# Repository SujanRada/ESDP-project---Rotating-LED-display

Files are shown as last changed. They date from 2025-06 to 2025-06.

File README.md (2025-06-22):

# Rotating LED Display

## Abstract

- Compact, disc-sized device  
- Rotates using CD/BLDC motor  
- Uses 56 RGB LEDs to display images, time, weather, and data from the internet  
- Wirelessly powered  
- Controlled via user-friendly web interfaces  
- Uses ESP-32 and RP-2040 microcontrollers
  
### BOM:
https://iith-my.sharepoint.com/:x:/g/personal/ee23btech11220_iith_ac_in/Eb25p-EQcuBLmObKBZ19a6YB39MDdF6vqVOBd3wfBGQ2Pw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

## Description of the Device

- Two primary units:
  - Power supply unit (stationary)
  - Display board (rotates)

- Wireless power using inductive coupling  
- Display board is rotated using a DC motor  
- Energy is wirelessly transmitted from the power supply unit to the display board, eliminating the use of wired connections  
- Display board has a row of 56 LEDs used for display. As the board rotates, the LEDs light up to create full images using the POV (Persistence of Vision) effect  
- LED operations are controlled by the RP-2040  
- ESP32 controls the display content, image decoding, and Wi-Fi connectivity (maintains an internet connection)  
- Images are stored on a microSD card  
- Web interface hosted by ESP32 (mini web server). Users can access it via any browser to:
  - Enter/change Wi-Fi credentials
  - Upload and manage files
  - Modify display settings
 
## Device
<p align="center"> 
  
</p>
<p align="center"> 
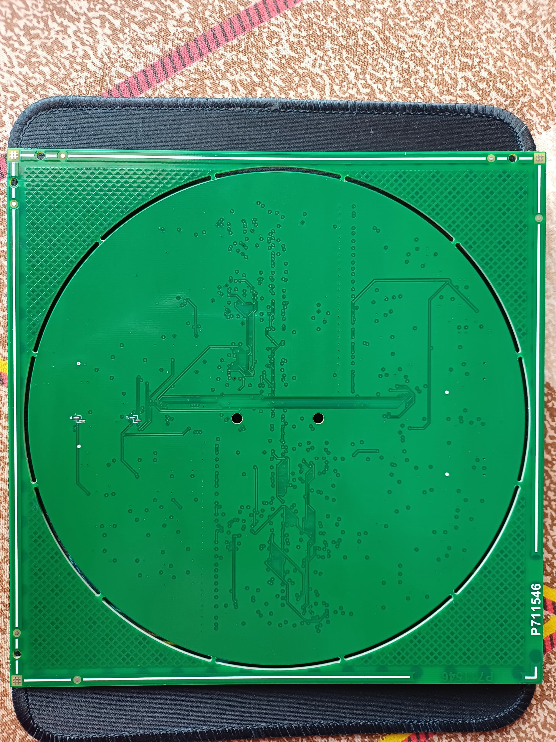
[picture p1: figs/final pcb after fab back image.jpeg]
  
</p>

## Schematics using KiCAD

### 3.3V and 5V step down buck converter schematics
<p align="center"> 
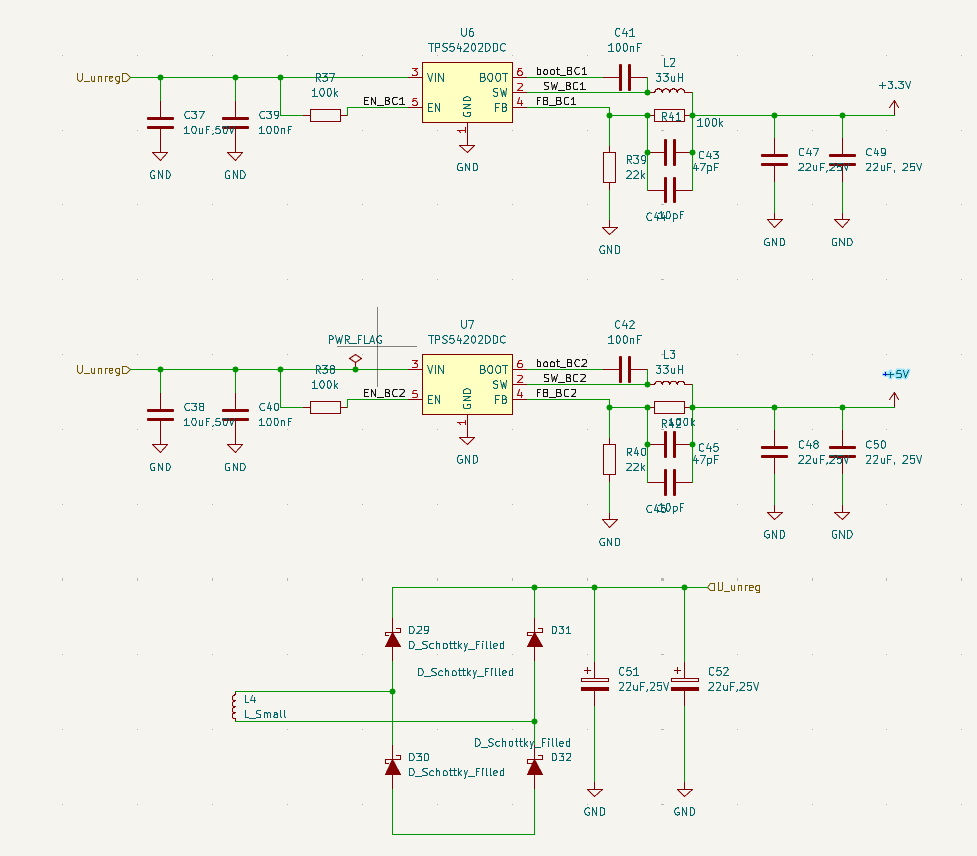
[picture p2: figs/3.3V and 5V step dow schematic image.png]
  
</p>

### ESP32-S3 microcontroller schematic
<p align="center"> 
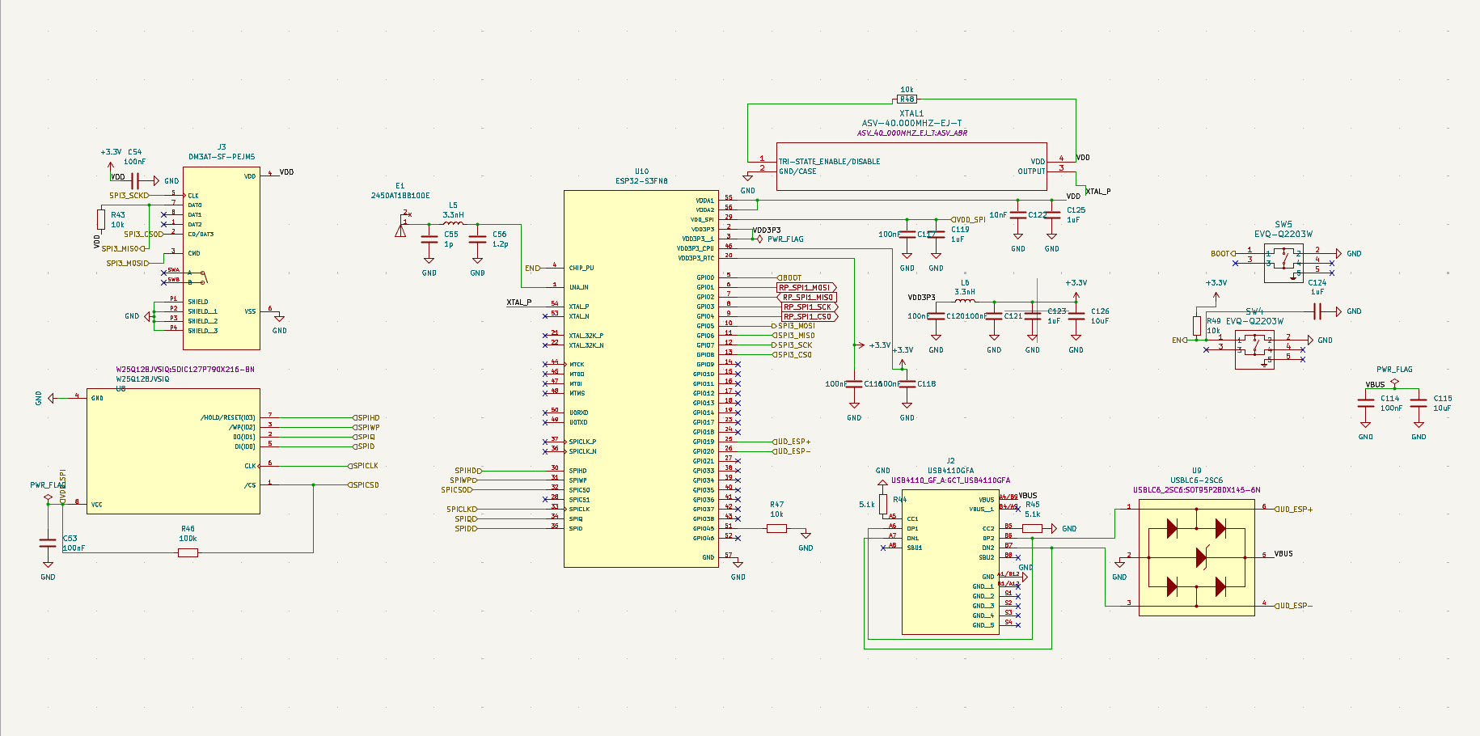
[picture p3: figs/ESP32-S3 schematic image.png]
  
</p>

### RP2040 microcontroller schematic
<p align="center"> 
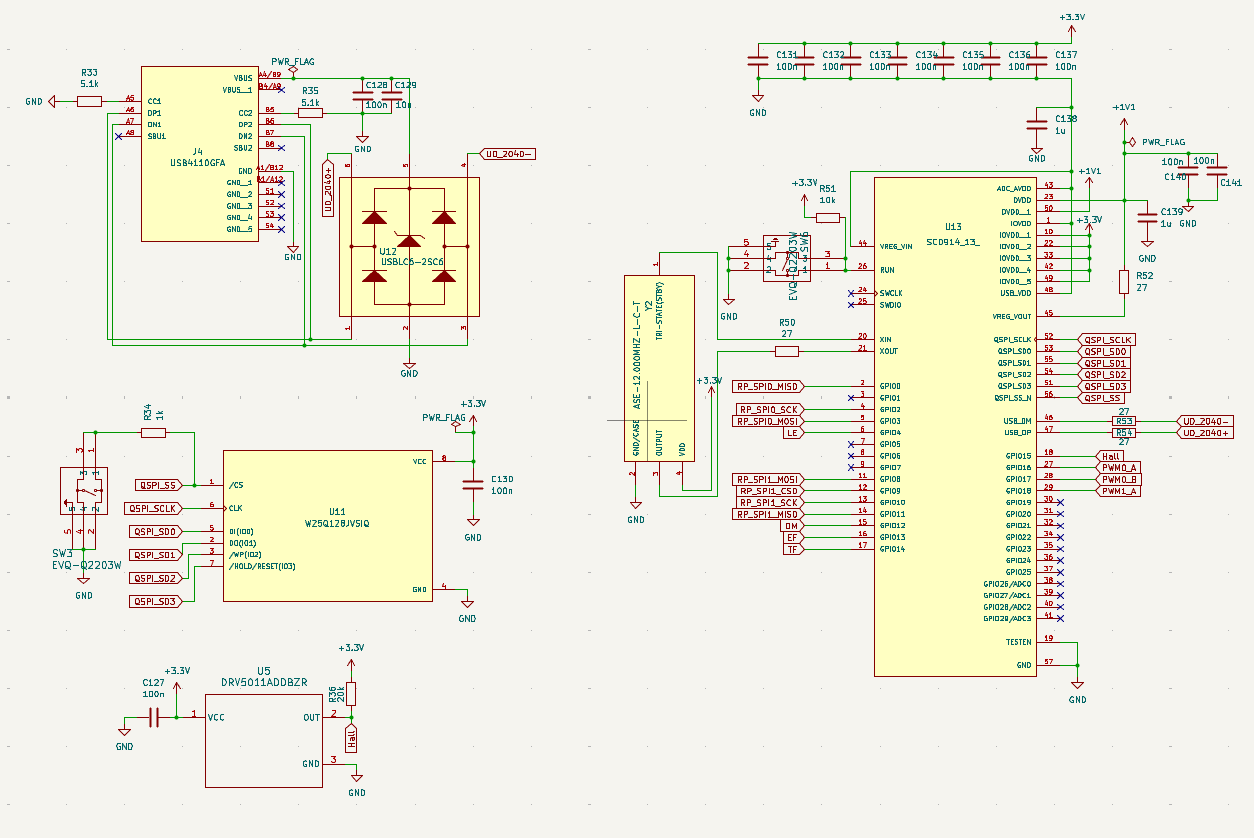
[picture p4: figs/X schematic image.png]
  
</p>

### STP24DPO5BTR IC schemaics
<p align="center"> 
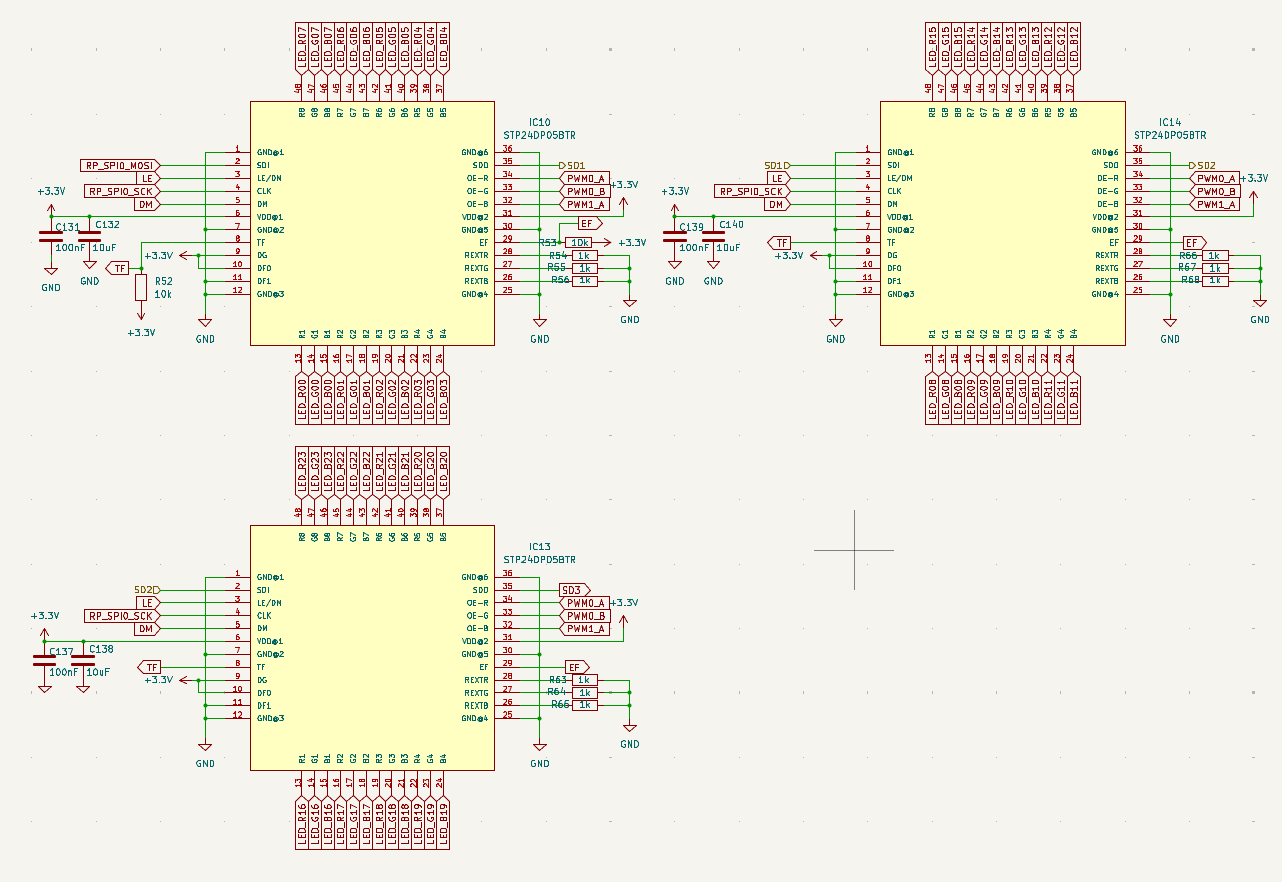
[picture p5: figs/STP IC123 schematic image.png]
  
</p>
<p align="center"> 
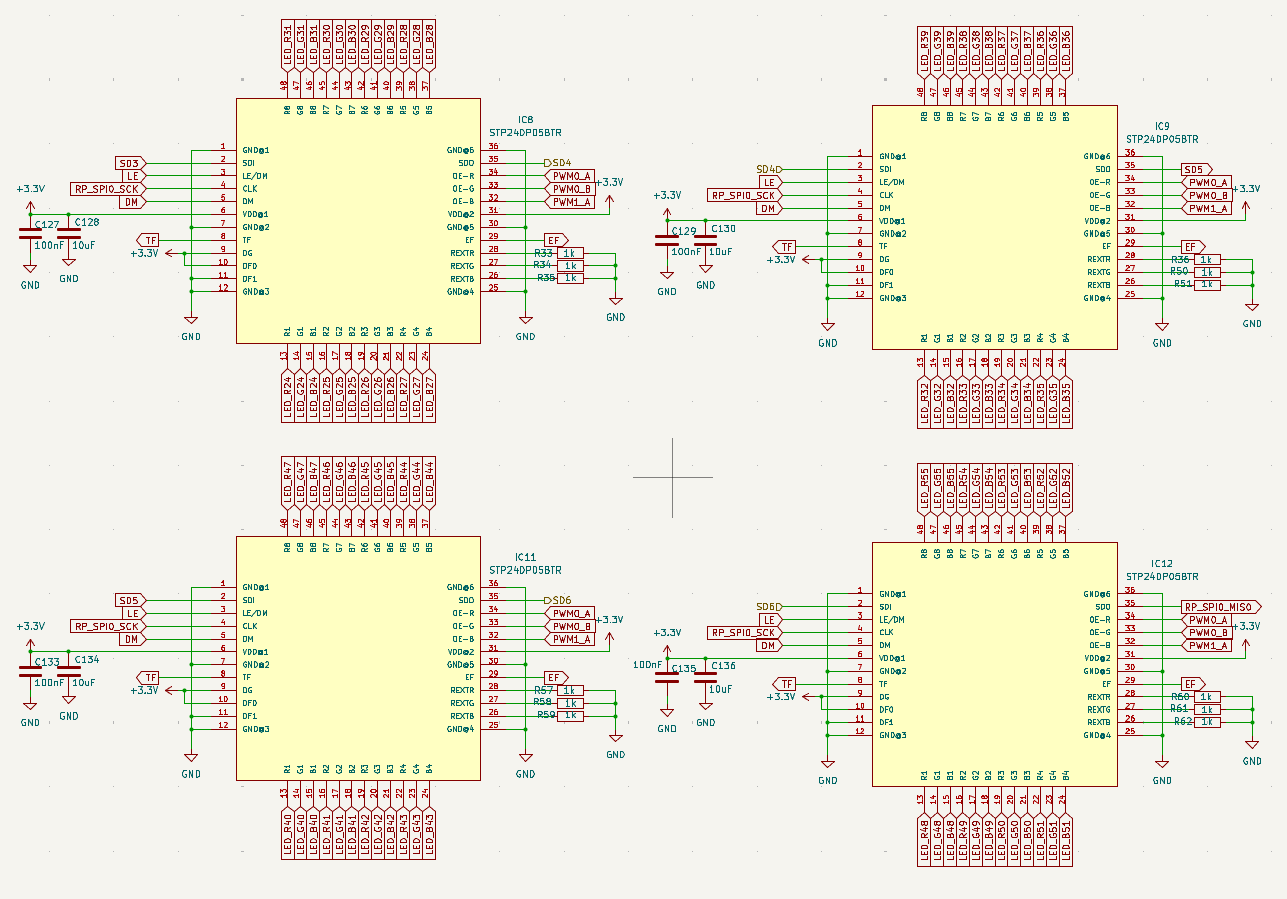
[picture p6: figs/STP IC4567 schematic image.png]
  
</p>

### LED connection schematics
<p align="center"> 
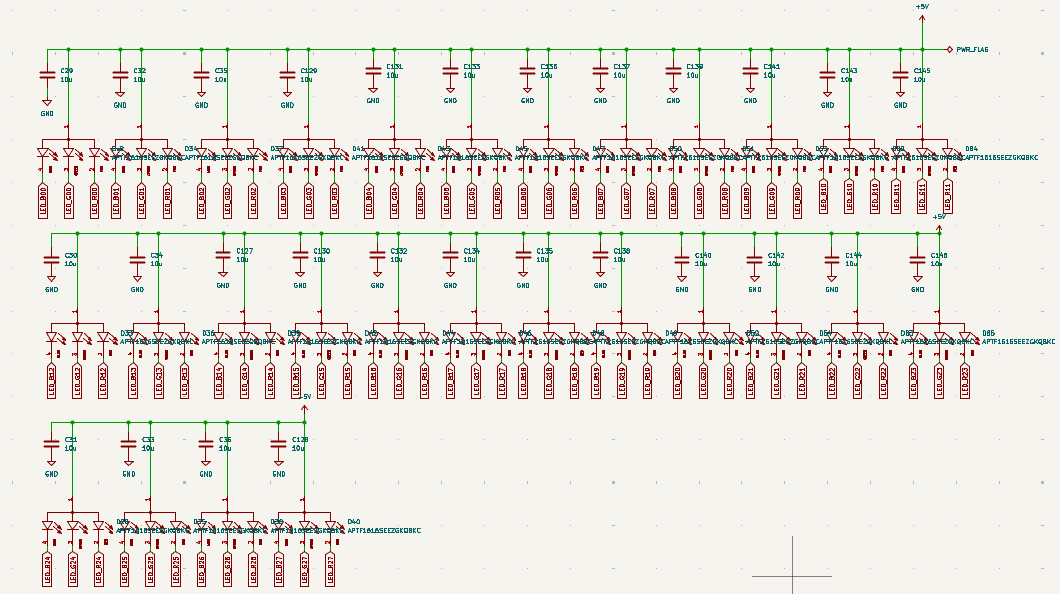
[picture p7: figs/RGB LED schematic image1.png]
  
</p>
<p align="center"> 
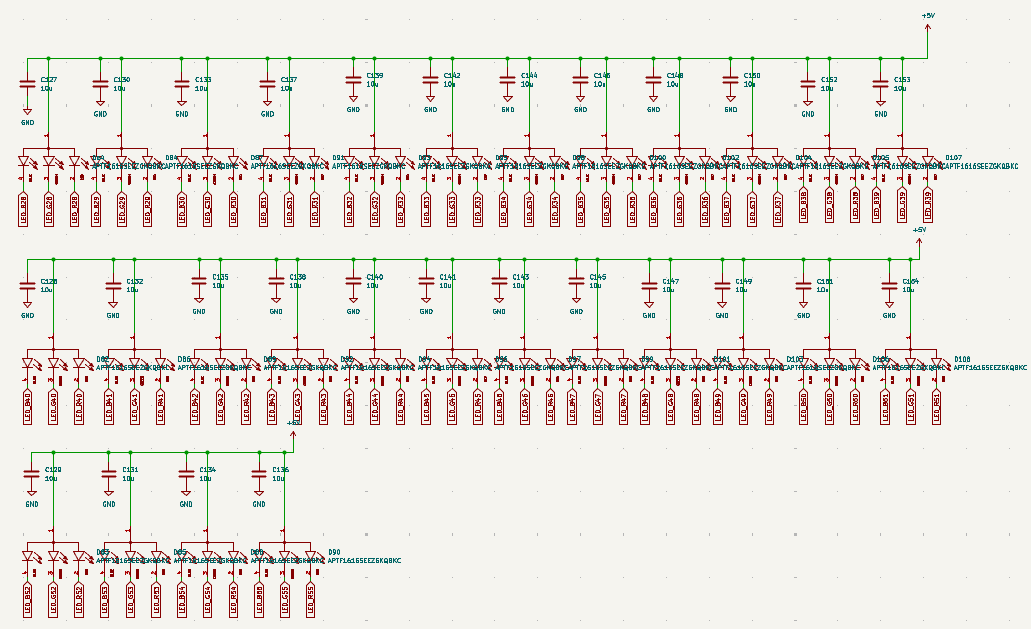
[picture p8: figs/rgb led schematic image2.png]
  
</p>

## PCB design and layout

### Front layer layout
<p align="center"> 
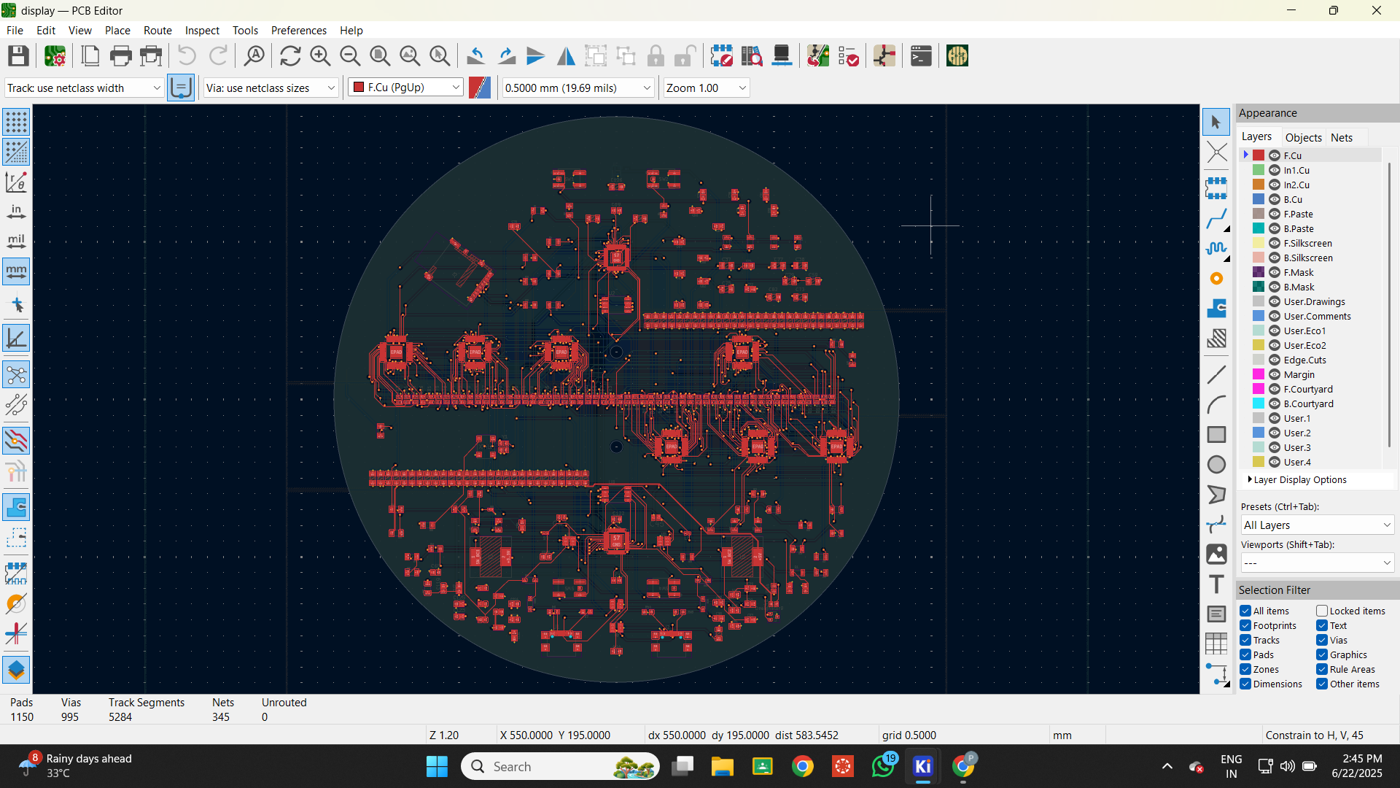
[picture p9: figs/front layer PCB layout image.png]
  
</p>

### GND layer PCB layout
<p align="center"> 
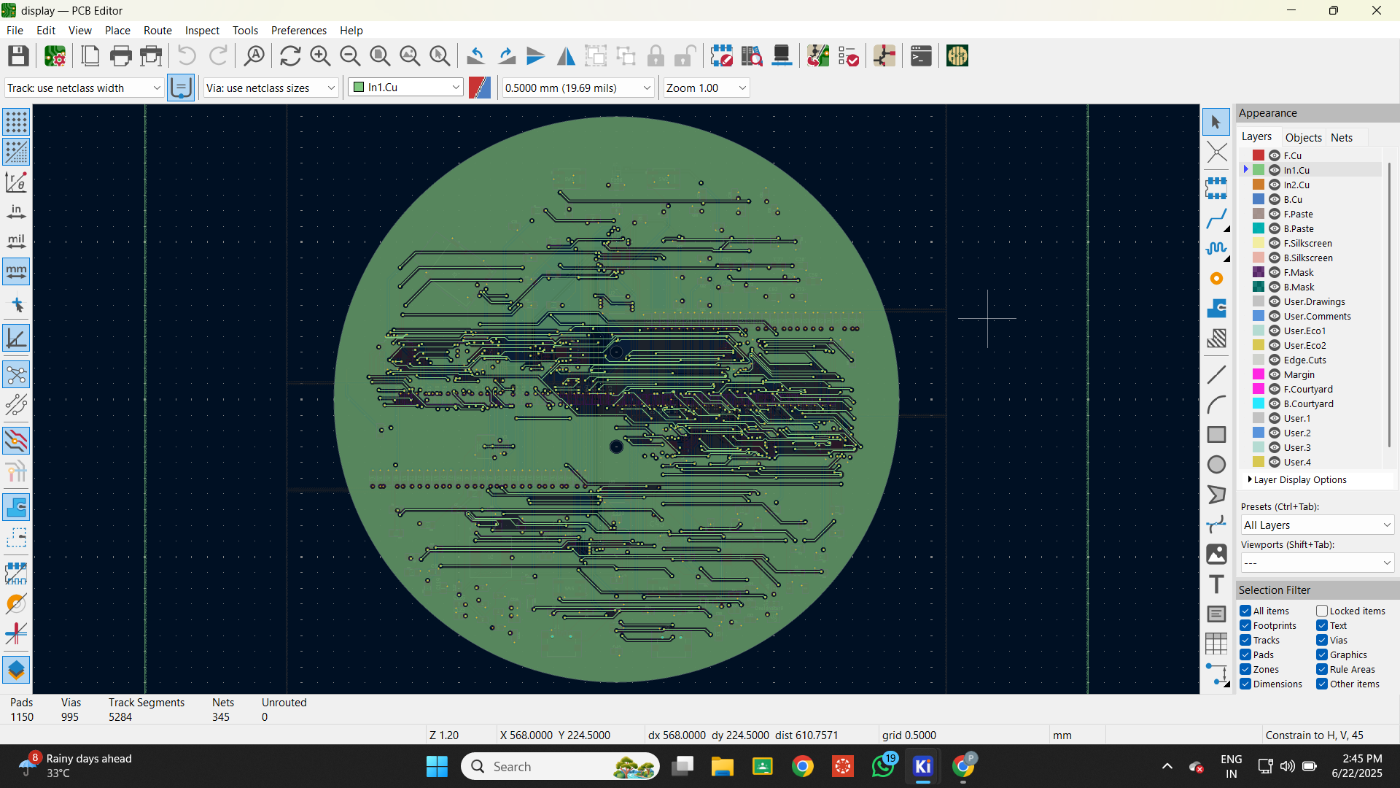
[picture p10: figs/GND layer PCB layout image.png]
  
</p>

### 3.3V and 5V layer PCB layout
<p align="center"> 
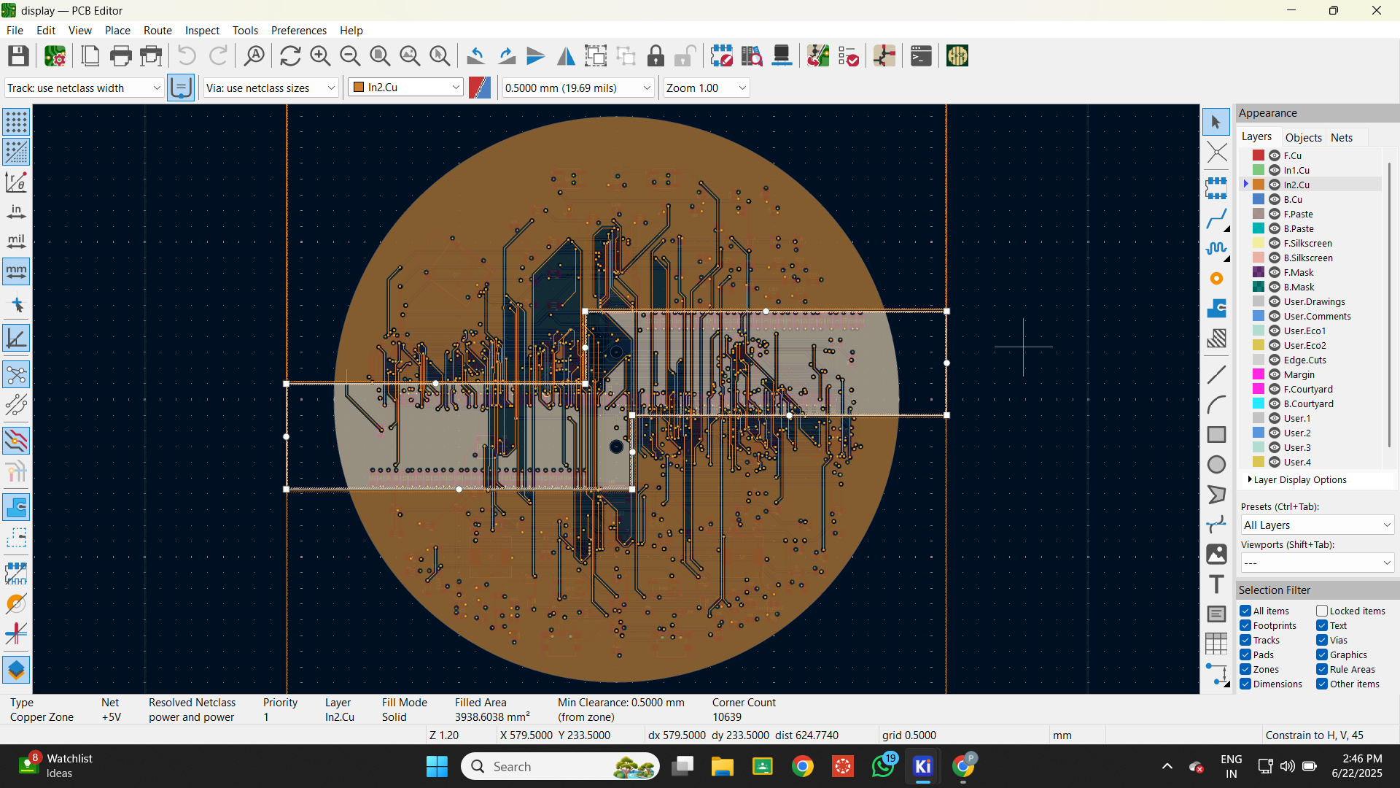
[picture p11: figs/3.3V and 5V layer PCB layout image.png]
  
</p>

### back layer PCB layout
<p align="center"> 
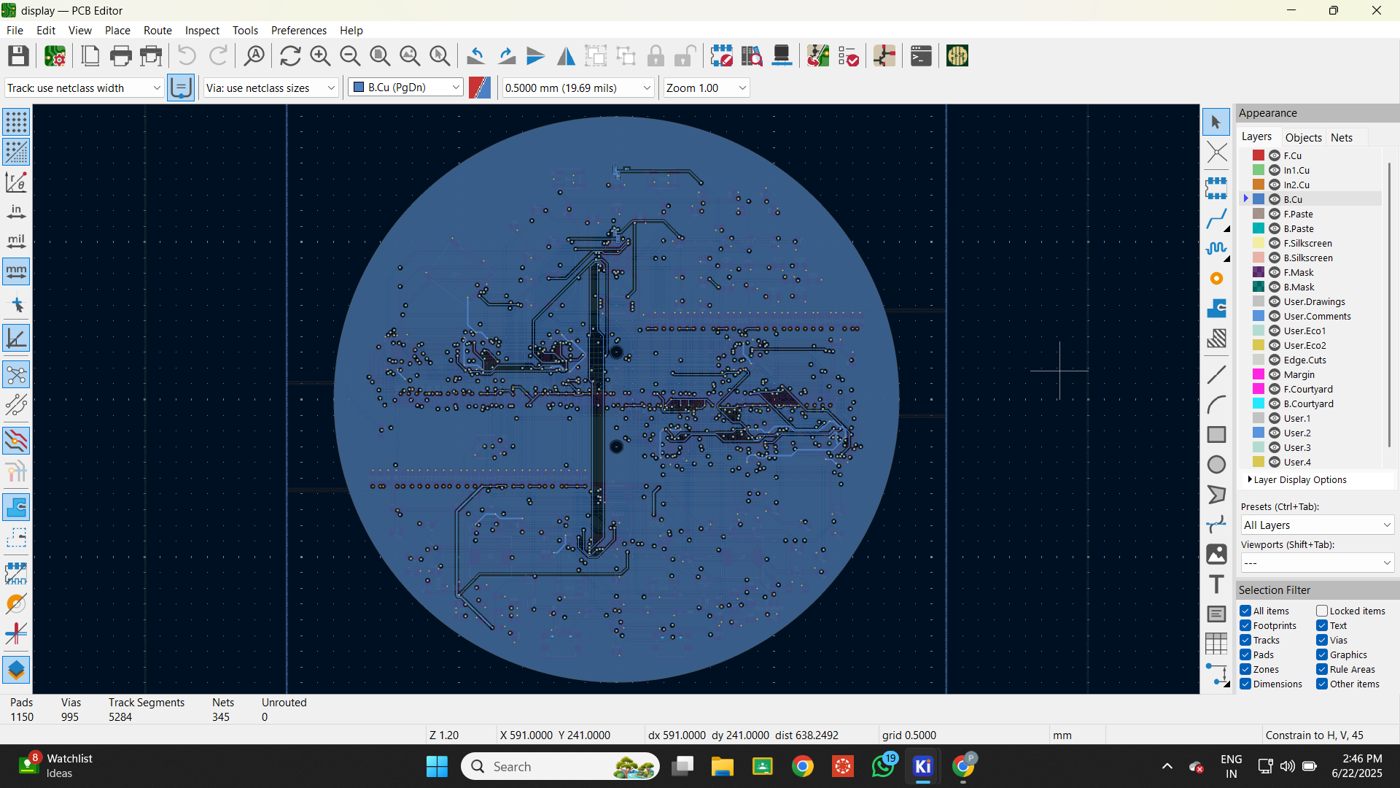
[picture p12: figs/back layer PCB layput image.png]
  
</p>

### Final PCB 3D view
<p align="center"> 
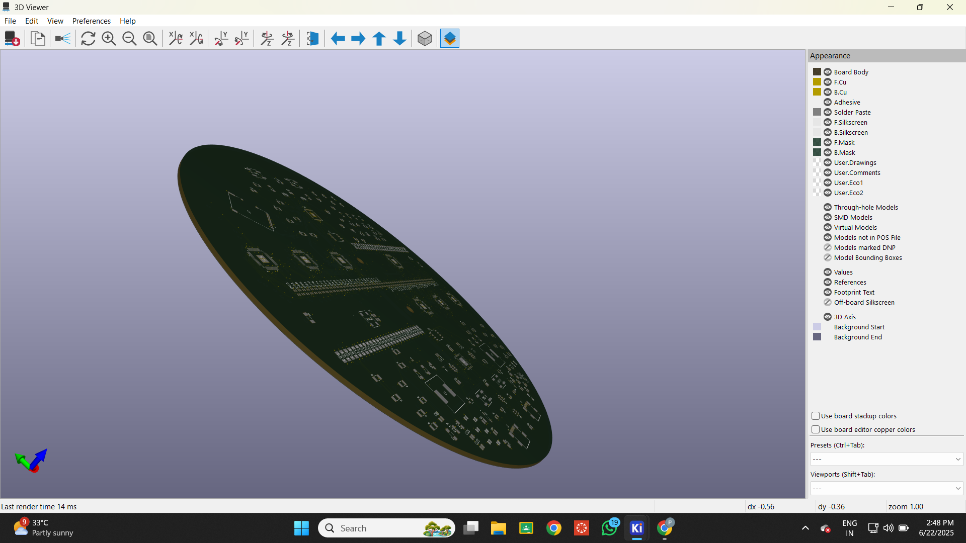
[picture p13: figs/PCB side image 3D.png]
  
</p>
<p align="center"> 
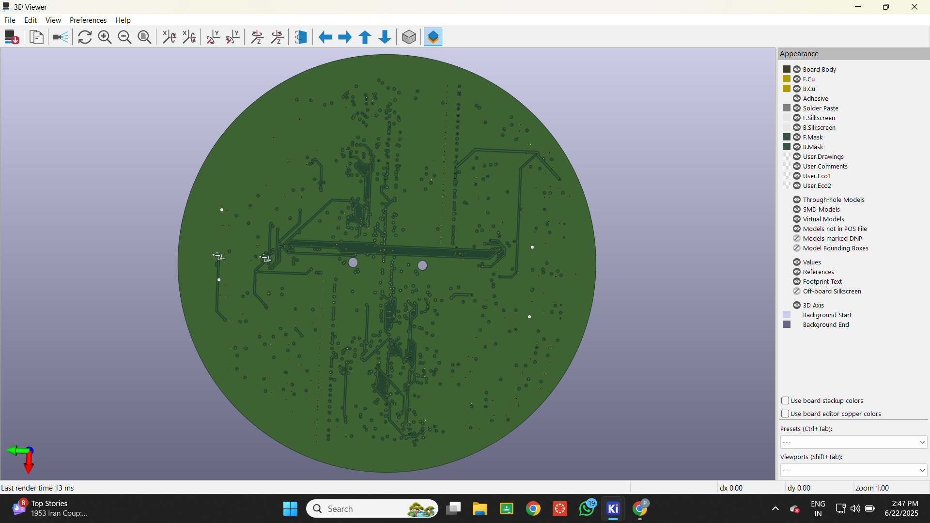
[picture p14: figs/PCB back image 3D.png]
  
</p>

## Operating Modes

### BOOT Behavior and Wi-Fi Setup

- On startup, the device tries connecting to a known Wi-Fi network.
- If no valid credentials are found, it enters **Access Point (AP) mode**.

  **AP Mode Details:**
  - **SSID:** ESDP40  
  - **Password:** *(None — open network)*

- To configure:
  1. Connect your PC or mobile device to the `ESDP40` Wi-Fi network.
  2. Open a web browser and navigate to the IP address shown on the device display.

#### Web Interface (Hosted by ESP32)

- Enter Wi-Fi credentials
- View the device's IP address (if connected to local Wi-Fi)
- Upload images and modify display configurations
- Switch between available display modes
- Manage files stored on the SD card

### Display Modes

- **LOGO Clock Mode:**  
  Displays an analog clock face along with a customizable logo or image

- **Analog Clock Mode:**  
  Shows a traditional clock face with customizable visuals

- **Weather and Time Mode:**  
  Displays current time, weather information, and charging status

### Mode Configuration

All display modes and system settings can be configured via the web user interface.

## Mechanical Design

- The mechanical design consists of two main assemblies:
  - **Power Supply Board** (stationary)
  - **Display Board** (rotating)

- A potentiometer is included to control the rotation speed.

- **Wireless Power Alignment:**
  - The secondary coil on the back of the rotating board aligns with the primary coil on the base.
  - Power is transferred inductively (eliminates twisting wires).

- **Symmetrical Component Placement:**
  - Ensures smooth rotation and proper balance.
  - Aligns the center of mass (COM) with the rotational axis.
  - Any imbalance in materials can cause the disc to wobble, affecting display clarity and mechanical durability.

### LED Specifications

- 56 rectangular RGB LEDs, each approximately **1.6 mm wide**  
- Placed on a **2 mm pitch/grid**  
- The LED row is shifted by **0.5 mm** (not centered)

**Why the 0.5 mm shift?**

- When the disc spins 180°, the 0.5 mm offset causes the LED row to align in between the previous positions, effectively reducing the radial pitch from 2 mm to 1 mm.
- This creates a **rotational interlacing effect**:
  - **Doubles the radial resolution** (from 2 mm to 1 mm)
  - **Doubles the effective frame rate** by smoothly overlapping alternating frames

### Image Synchronization

- The software requires precise rotational phase information to display images correctly.

- A **Hall sensor** detects the "zero" or **home position** and generates a trigger pulse to indicate the start of a new frame.

**Trigger Pulse Function:**

- Resets the angular position counter to **0°**
- Starts a new frame/image rendering
- Controller updates LEDs at **precise angular intervals** until the next pulse, ensuring stable and synchronized visuals

> ⚠️ If the trigger pulse is noisy or misaligned, it may result in flickering or wobbly visuals.

## Electronics Architecture
<p align="center"> 
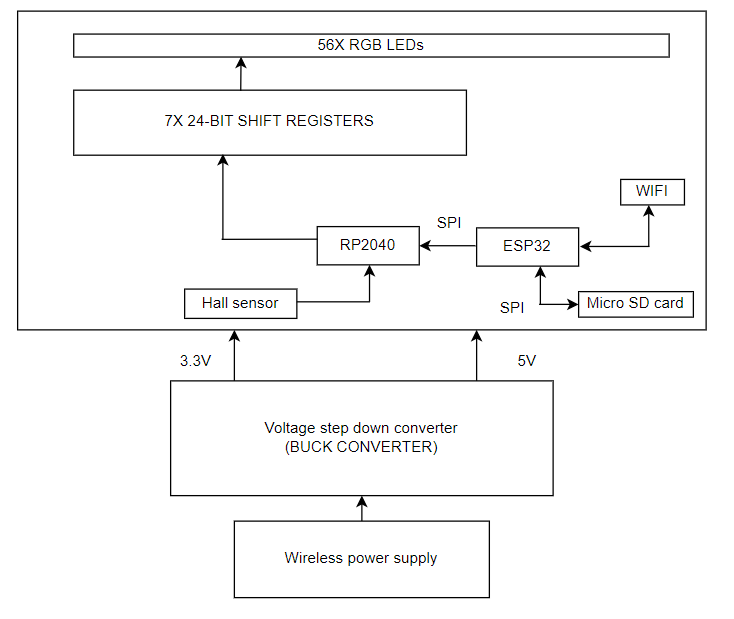
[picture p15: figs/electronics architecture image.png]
  
</p>

- A **12–24V DC input** powers the entire system.

### Components

- **Variable Step-Down Converter**  
  - Adjusts voltage to drive the motor that spins the display.

### Receiving End (on Rotating Display Board)

- AC from wireless coil → **Rectified to DC** → Passed through:
  1. 5V step-down DC converter
  2. 3.3V step-down DC converter  
  → Powers **microcontrollers** and **LEDs**

---

## Display Assembly

### LED Path Control

- 56 RGB LEDs managed using **7 × 24-bit shift registers**
  - Each shift register controls 8 RGB LEDs  
    (3 colors × 8 LEDs = 24 bits per register)

### RP2040 Microcontroller

- Interfaces with shift registers via **SPI**
- Sends data and clock signals to control LEDs
- Uses **hall sensor** input to trigger LED updates at precise angular positions

### Image Generation Path

- **ESP32-S3 Microcontroller**:
  - Connects to the internet via Wi-Fi
  - Reads image data from a **microSD card**
  - Sends image frames to RP2040 over SPI

### Synchronization

- A **hall-effect sensor** detects fixed positions each rotation
- Sends a **trigger signal** to the RP2040 to:
  - Reset angular position
  - Ensure correct image alignment and smooth refresh

---

### Flow Summaries

#### 🔌 Power Flow:
12–24V DC → Wireless Power Supply → Wireless Coil → Rectifier → 5V/3.3V Regulators → Electronics

#### 🔄 Data Flow
ESP32 → SPI → RP2040 → SPI → Shift Registers → LEDs

#### ⏱️ Timing Flow
Hall Sensor → Trigger → RP2040 → Synchronized LED Updates

---

## Power Supply Unit
<p align="center"> 
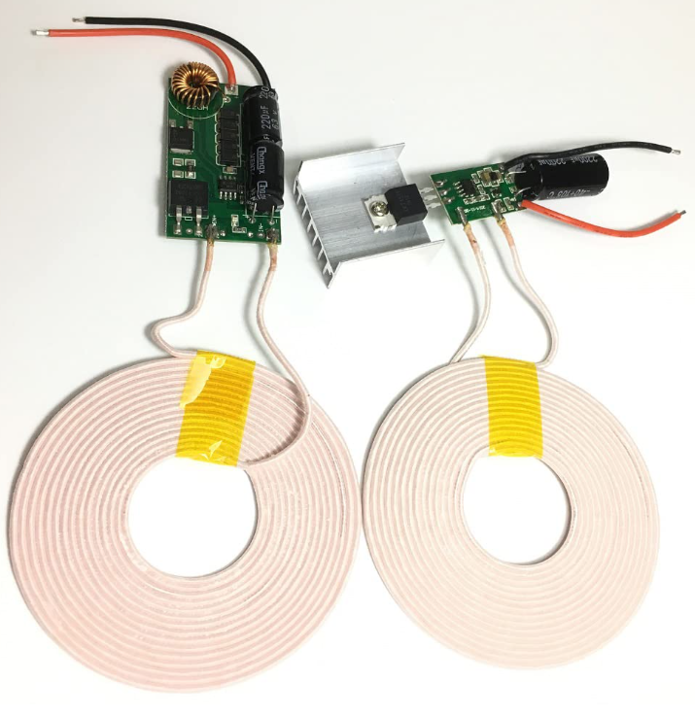
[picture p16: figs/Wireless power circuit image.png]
  
</p>

We are using a pre-made 12V 3A Long-Distance Wireless Power Supply Module to deliver power wirelessly.

**Key Specifications:**
- Input voltage: 24V  
- Output: 12V @ 3A (max), 36W  
- Coil size: Outer diameter 82 mm, Inner diameter 30 mm  
- Transmitter board size: 17 mm × 30 mm  
- Receiver board size: 30 mm × 54 mm  

**Note:** Maintain a minimum distance of 5 mm between the coils. Distances less than 5 mm can cause over-voltage and damage the module.

**Distance vs Output Current (12V):**

| Distance (mm) | Current (A) |
|---|---|
| 5–11 | 3.2–3.0 |
| 12–15 | 3.1–2.5 |
| 16–20 | 2.3–1.6 |
| 21–25 | 1.5–1.1 |

## Display Board
<p align="center"> 
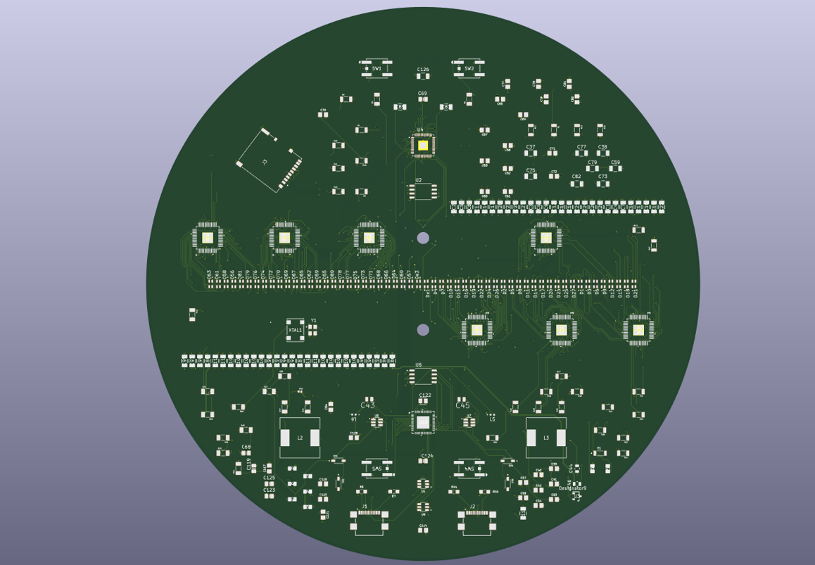
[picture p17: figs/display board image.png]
  
</p>

### LEDs

- 56 RGB LEDs → 7 cascaded **24-bit shift registers**
- Registers load **serial data** from an SPI interface of the **RP2040**
- RP2040 controls **separate enable signals** for R, G, B LEDs
- Each shift register controls 8 RGB LEDs  
  → 8 LEDs × 3 colors = 24 bits
- **Shift Register Used:** `STP24DP05BTR`
  - Controls up to **24 LEDs**
  - Ensures **stable current** for each LED channel
  - Works with MCUs like RP2040 via SPI
  - Features: **PWM dimming**, **thermal protection**, **open LED detection**

> **Current Sink?**  
> Yes — STP24DP05BTR pulls current through LEDs to ground.  
> LED anodes connect to Vcc, cathodes to STP outputs (OUT0 to OUT23).

> **How many LEDs per register?**  
> Each RGB LED = 3 channels  
> → 24 / 3 = 8 RGB LEDs per chip  
> → 56 RGB LEDs → 7 × STP24DP05BTR chips

---

### Current Control

- Each LED channel draws **20mA**
- Max per shift register = 24 × 20mA = **480mA**
- Total max = 56 LEDs × 3 × 20mA = **3.36A @5V** = **16.8W**  
  > *Exceeds wireless power capability!*
- Brightness is controlled via **PWM (duty cycle)** using RP2040
- Separate RGB **enable signals** allow **white point correction**

---

### Displaying Color

- Uses **additive color mixing**
  - e.g., Red + Green = Yellow
- LEDs are binary (on/off), brightness is adjusted by **PWM**
- Each pixel → divided into **8 sub-pixels**
  - 8 brightness levels per R, G, B channel  
  → 8 × 8 × 8 = **512 colors**
- Display: **56 radial pixels**, **240 angular pixels**

---

### Timing, Interrupts, and Synchronization

#### SPI Timing

- SPI clock: **25 MHz**
- 56 RGB LEDs = 168 bits (56 × 3)
- Transfer time ≈ `168 / 25 MHz ≈ 6.7μs`

#### Rotation Speed

- Max rotation speed: **1200 RPM**
  - 1200 / 60 = 20 rev/sec
  - Time per rev = **50ms**
- Angular resolution = 240 pixels × 8 subpixels = **1920 updates**
- Time per LED update = `50ms / 1920 ≈ 26μs`
  - SPI takes only **6.7μs**  
  → Leaves time for logic/latency handling

---

### RP2040 Software (C-based)

- Uses **2 main interrupt routines**:
  1. `HALLIRQ` (Hall Sensor Interrupt)
  2. `PIXELIRQ` (Timer Interrupt)

#### 1. HALLIRQ

- Triggered **once per rotation** by the hall sensor
- Marks **start of new rotation**
- Measures **time per turn** (tpt)
- Calculates `time_per_update = tpt / 1920`
- Configures hardware timer
- Starts 1920 pixel updates using timer

#### 2. PIXELIRQ

- Runs every `1/1920` of a turn
- Sends **168-bit LED pattern**
- Updates LEDs to show **one sub-pixel** of one angular column
- Tracks updates to complete a full cycle
- Repeats when next `HALLIRQ` is triggered

---

### Why Use a Hardware Timer?

*Content coming soon...*

---

### Controlling Brightness (White Balancing)

*Content coming soon...*

### ESP32-S3 for Internet communication and image generation

*Content coming soon...*

### Programming of the microcontrollers

*Content coming soon...*

## The Software of the ESP32

*Content coming soon...*

## CAD model used for constant and stable wireless power
<p align="center"> 
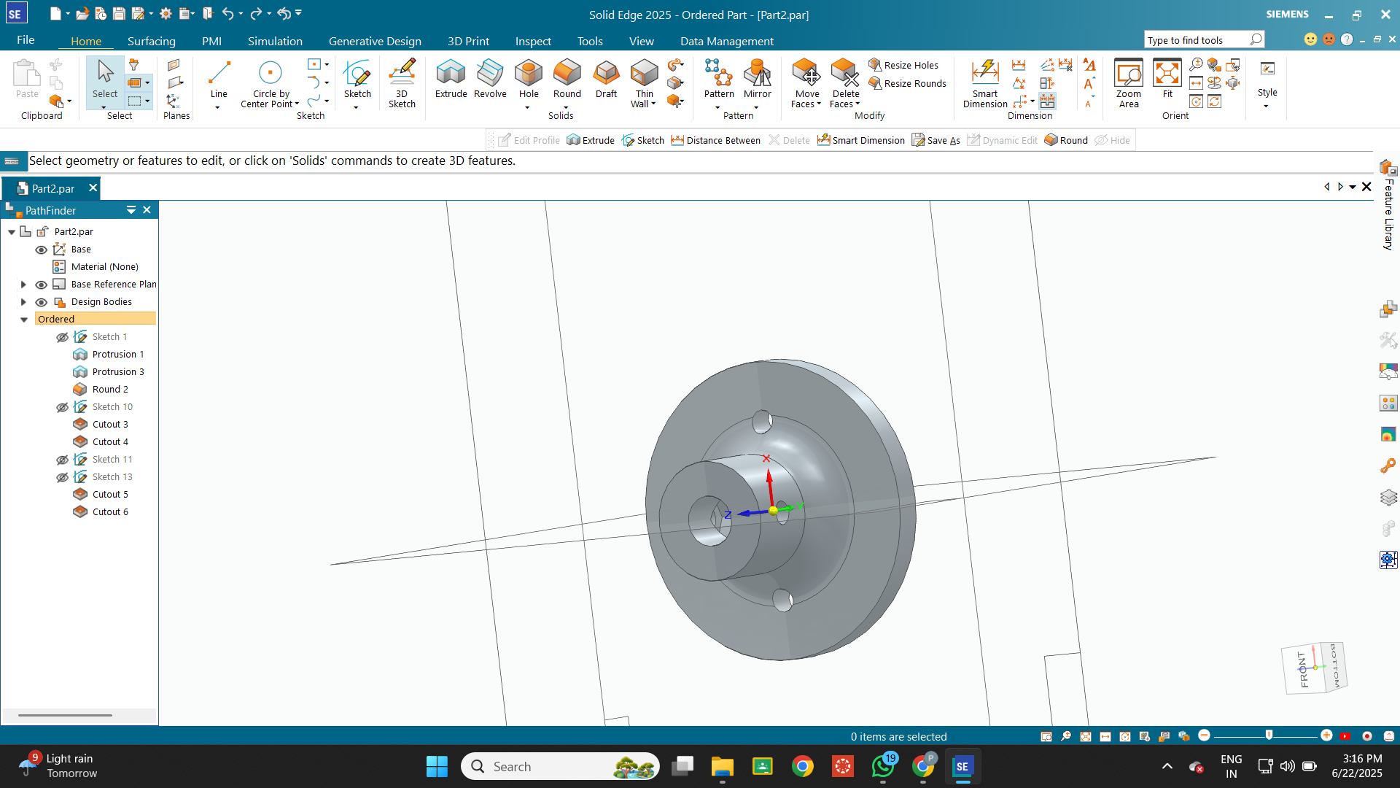
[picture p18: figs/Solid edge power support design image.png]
  
</p>
<p align="center"> 
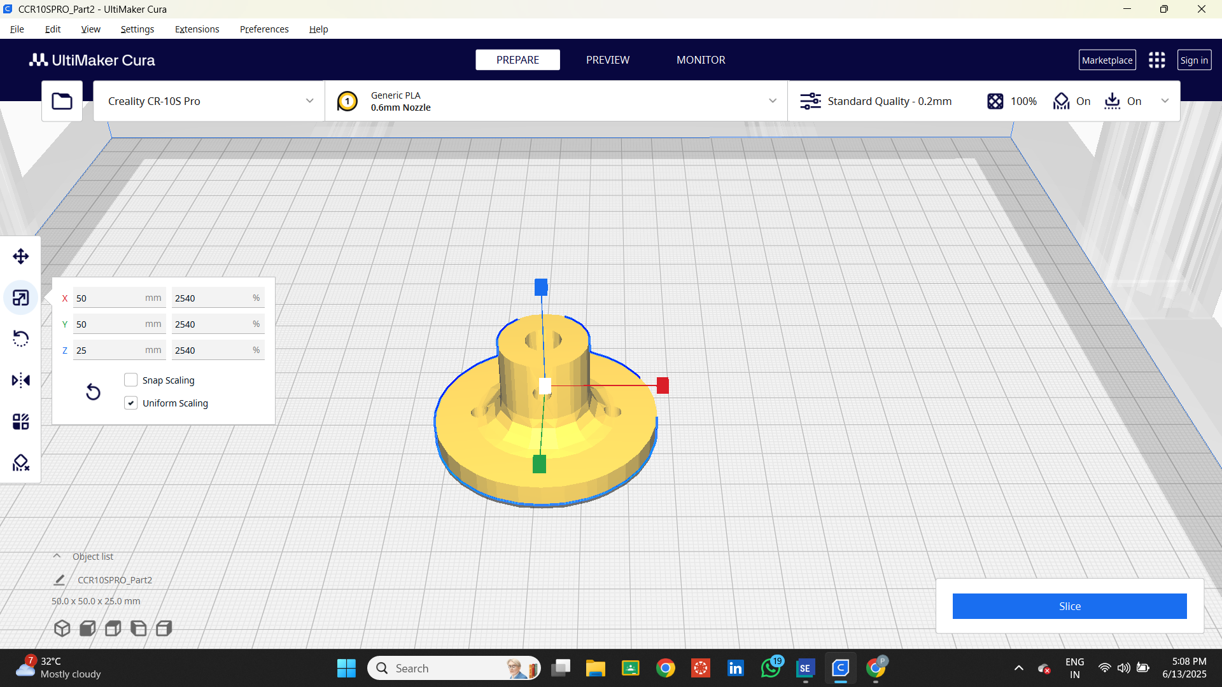
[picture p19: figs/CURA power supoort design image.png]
  
</p>

## Testing

### Wireless power testing
<p align="center"> 
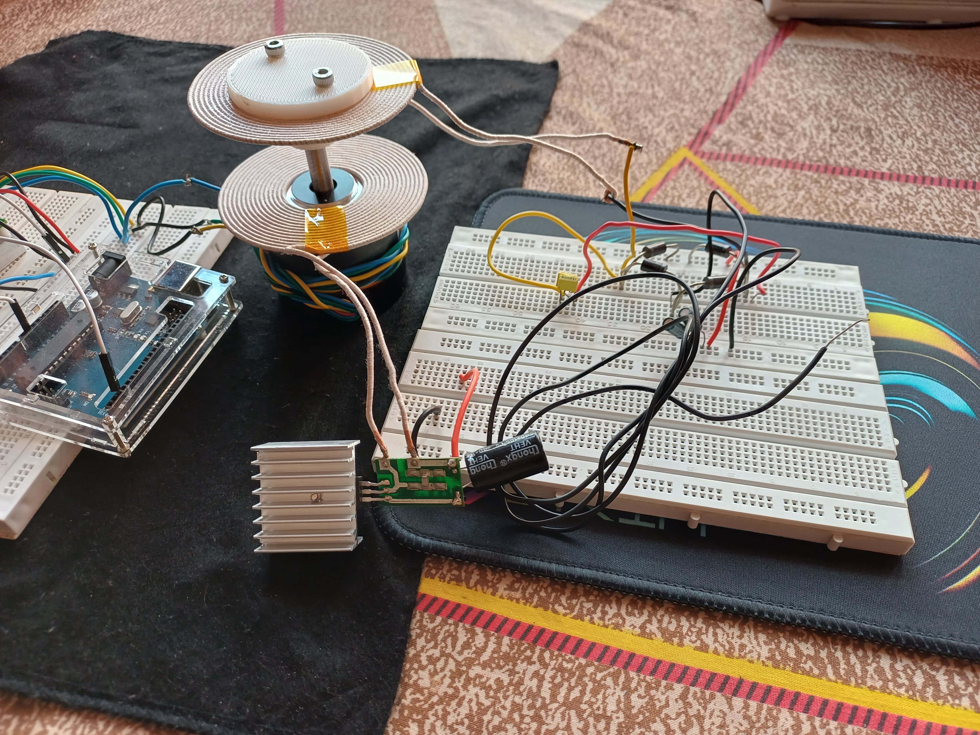
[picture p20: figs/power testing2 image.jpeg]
  
</p>

### BLDC motor testing
<p align="center"> 
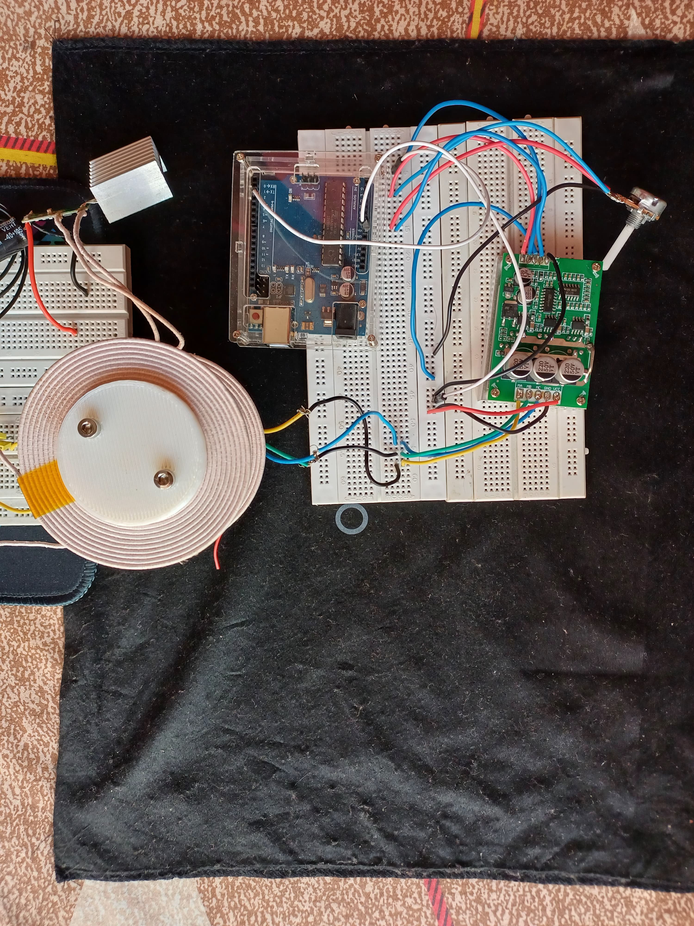
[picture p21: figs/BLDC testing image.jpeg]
  
</p>

### Testing the combined circuit and checking RPM
<p align="center"> 
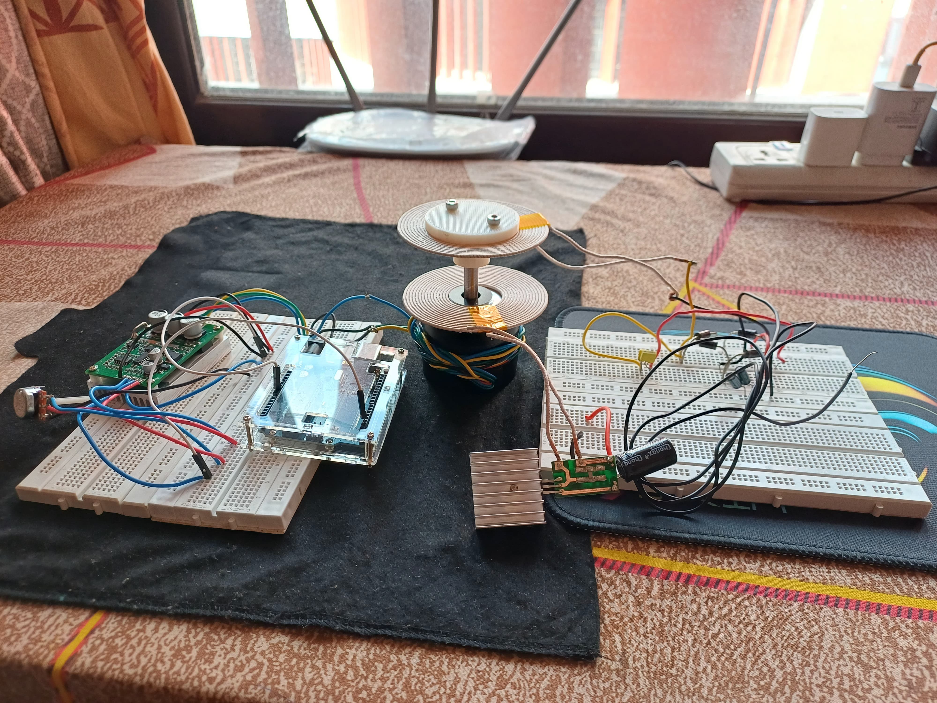
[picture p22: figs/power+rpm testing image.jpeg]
  
</p>

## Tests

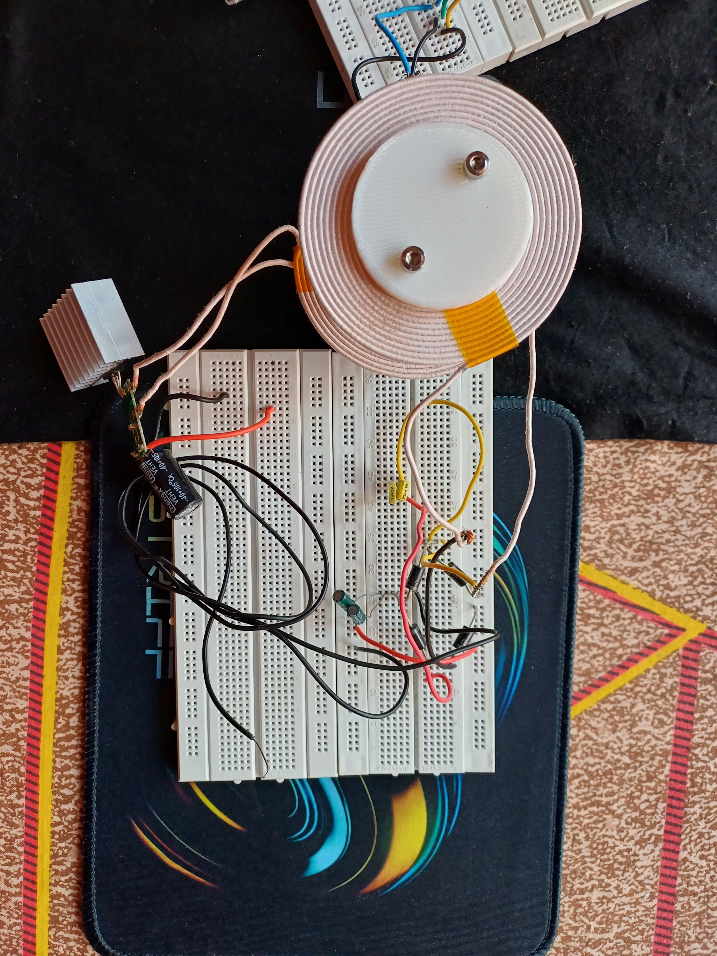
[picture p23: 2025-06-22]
figs/power testing1 image.jpeg

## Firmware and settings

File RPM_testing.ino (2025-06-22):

volatile unsigned int pulseCount = 0;
unsigned long lastMillis = 0;
float rpm = 0.0;

void countPulse() {
  pulseCount++;
}

void setup() {
  pinMode(2, INPUT_PULLUP);  // Signal from speed pin
  attachInterrupt(digitalPinToInterrupt(2), countPulse, RISING);
  Serial.begin(38400);
}

void loop() {
  unsigned long currentMillis = millis();

  // Calculate every 1 second
  if (currentMillis - lastMillis >= 1000) {
    noInterrupts(); // Stop interrupt while reading shared variable
    unsigned int count = pulseCount;
    pulseCount = 0;
    interrupts();

    rpm = count * 5.0;  // Since 12 pulses per mechanical revolution

    Serial.print("RPM: ");
    Serial.println(rpm);

    lastMillis = currentMillis;
  }
}
